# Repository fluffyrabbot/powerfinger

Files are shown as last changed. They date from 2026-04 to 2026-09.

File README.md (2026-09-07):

# PowerFinger

**Open-source assistive input devices. Under $25 BOM. Build one for anyone who
needs it.**

PowerFinger is a family of wearable and handheld pointing devices designed for
accessibility, repairability, and surface agnosticism. Hardware design files —
schematics, PCB layouts, 3D models, BOMs, and assembly docs — are published
under CERN-OHL-S 2.0. Firmware and software, including the companion app, are
published under MIT.

**Primary validation claim:** a user with limited wrist mobility can browse,
click, drag, and scroll on everyday surfaces without host-side remapping
software.

## Philosophy

Computer input is a solved problem for people who can sit at a desk and grip a
mouse. For everyone else — people with limited wrist mobility, repetitive strain
injuries, tremors, amputations, arthritis, or simply no desk — it isn't.

Existing assistive input devices cost $100–$350 and are closed, proprietary, and
fragile. When the vendor disappears, the device becomes e-waste and the user
loses their interface to the digital world.

PowerFinger treats input devices as **prosthetics for digital agency**. The more
redundant ways people have to control things the way they find most natural, the
better as a common good. We design for:

- **Affordability.** $9–$25 BOM depending on variant. The cheapest ring is under
  $10 in components. The first two-ring validation lane targets ~$24 total.
- **Universal design.** Every device works for able-bodied users at their desk
  AND for users with specific accessibility needs. No separate "disability"
  product line.
- **Surface agnosticism as a spectrum.** The optical ring works on most opaque
  surfaces (not glass). The ball+Hall variants are intended for glass, fabric,
  and skin, but those claims stay provisional until the surface protocol is run.
  The IMU variant needs no surface at all. Each variant's limitations are
  documented honestly — see
  [docs/COMBINATORICS.md](docs/COMBINATORICS.md).
- **Composability.** One ring is a mouse. Two rings are a mouse + scroll wheel.
  Three rings are a configurable control surface. The system grows with the
  user's needs.
- **Repairability.** Every part is replaceable. 3D-print a new shell, swap a
  battery, reflash firmware. No planned obsolescence.
- **Privacy.** Fully offline operation. No cloud, no telemetry, no account. Your
  movement data stays on your device.

## Active Program

### Active Validation Lane

- `R30-OLED-NONE-NONE` optical ring pair plus `USB-HUB`
- Goal: prove the no-host-remapping cursor + click + scroll workflow first
- Source of truth: [docs/ACTIVE-LANE-CHECKLIST.md](docs/ACTIVE-LANE-CHECKLIST.md)

### Hedge Lane

- `WSTD-BALL-NONE-NONE` wand
- Use this lane only after the active ring + hub lane clears its gates or if
  the ring fails package-closure / safety reality in a way that forces a
  productization pivot

### Deferred Until Gate 6

- Ball+Hall ring
- Puck variants
- Pro optical-on-ball ring
- OCR / camera and other rich companion features
- IMU hybrids and additional mountings beyond defensive publication coverage

## Form Factors

### Ring

Every ring has a tracking sensor + a click switch + BLE. One ring is the
single-device control loop. Two identical rings plus the hub are the primary
validation lane for the no-host-remapping workflow: cursor + left click on one
finger, scroll + right click on the other. Roles are assigned in software, not
hardware.

```
Middle finger (Ring 1):  move cursor + left click
Index finger  (Ring 2):  scroll      + right click
```

Everything else — drag, double-click, zoom, middle click, modifiers — is
software-defined combinations of those four primitives.

| Variant | BOM | Surface | Resolution |
|---|-----|---|---|
| Optical ring (P0) | ~$9 | Most opaque surfaces (not glass) | 800–2000 CPI |
| Ball+Hall ring (P1) | ~$11 | Target: glass, fabric, skin, and other hard cases | ~15–60 DPI |
| Optical-on-ball ring (Pro) | ~$17 | Target: any rollable surface, pending validation | Up to 12,000 CPI |

Only the optical ring is in the active validation lane. The other ring variants
remain documented for defensive publication and later research.

A USB hub dongle (~$6) is the intended path for composing two or more rings into
a single USB HID mouse without host-side remapping software.

### Wand

A pen-shaped BLE HID pointing device with a ball+Hall sensor at the tip. This
is the hedge lane: a handheld form factor designed for the surfaces and angles
that defeat optical pen mice. It is not the primary validation lane while the
ring + hub proof remains red. ~$14 BOM.

No existing product fills this space. Commercial pen mice ($35–150) use optical
sensors that fail on glass and degrade past ~20 degrees of pen tilt. Assistive
styluses only work on touchscreens. The wand is designed to work across glass,
fabric, blankets, tray tables, and other accessibility-relevant surfaces at
natural pen angles (30–70 degrees), but those claims stay gated until the
hardware protocol is run.

Pen grip reduces forearm pronation from ~42 degrees (flat mouse) to ~28 degrees
— clinically significant for carpal tunnel and RSI. An aluminum or stainless
steel body provides natural weight stabilization for tremor (same principle as
weighted assistive pens).

See [docs/WAND-COMPETITIVE.md](docs/WAND-COMPETITIVE.md) for the competitive
landscape, accessibility case, and patent analysis.

### Other Mountings

The electronics module is invariant; the harness adapts it to any body position.
The ring shell is just one harness. Others: toe ring, knuckle strap, wrist
bracelet, prosthetic mount, headband. Same PCB, same firmware, different
physical mounting. The companion app assigns meaning. These remain design-space
and defensive-publication coverage, not active implementation work.

See [docs/COMBINATORICS.md](docs/COMBINATORICS.md) for the full design space.

## Sensing Mechanisms

| Mechanism | Surface Agnostic? | Moving Parts | BOM | Resolution |
|---|---|---|-----|---|
| Mechanical ball + Hall effect | Target: glass, fabric, skin, and other rollable surfaces | Yes | ~$2 | Low (9–36 ticks/rev) |
| Direct optical (LED) | Most opaque surfaces | None | ~$0.50–4 | Good (800–2000 CPI) |
| Direct laser (VCSEL) | More surfaces than LED | None | ~$2–5 | Good (2000+ CPI) |
| Optical on captive ball | Target: any rollable surface, pending validation | Ball only | ~$5–8 | Excellent (12K CPI) |

## Deferred Capabilities

- **OCR camera** — scan text from physical books/documents, send to companion
  app for local OCR (Tesseract/PaddleOCR), translation, or text-to-speech.
  Requires companion app; pointing function works without it. Deferred until the
  active validation lane clears Gate 4.
- **Guidance laser** — red dot on the surface shows exactly where you're
  pointing/scanning. Deferred until the active validation lane clears Gate 4.

## What Exists Today

PowerFinger is still pre-prototype, but the repo already has a real software
lane. The main difference across directories is how much of each lane is
implementation versus planning:

| Area | Current reality | Start here |
|---|---|---|
| Firmware | Real ESP-IDF targets exist for `ring`, `hub`, `pen`, and `puck`; the verifier covers its own regression tests, host tests, companion protocol, sanitizers, active R30 profile, hub, and strict KiCad by default. | `scripts/verify-firmware-local.sh`, `docs/FIRMWARE-VERIFY-LOCAL.md` |
| Companion | A minimal local Web Serial app now lives under `companion/web/`. It talks to the hub's existing USB CDC text protocol and covers hub info, role assignment, swaps, forget, hub settings, per-ring tuning, live RSSI plus battery/diagnostics inspection, and hub-owned simultaneous-click gesture mapping. | `companion/README.md`, `companion/web/`, `docs/COMPANION-APP-ARCH.md` |
| Hardware | BOM intent files still anchor the lane, and each BOM-backed variant now has a hardware publication packet with a manifest plus assembly/disassembly baseline. The active `R30-OLED-NONE-NONE` ring and `USB-HUB` now also have first-board checklists and validation templates alongside their KiCad/OpenSCAD skeletons; routed PCBs and measured hardware evidence are still pending. | `hardware/README.md`, `hardware/bom/README.md` |
| Docs | Design, validation, accessibility, and IP docs are the most complete part of the repo today. | `docs/` |

## Quick Start

Install CMake, a C compiler, Python, Ruby, Node.js, and KiCad CLI for full local
verification. See [prerequisites and modes](docs/FIRMWARE-VERIFY-LOCAL.md).
Then install the pinned SDK and verify (reports go under `build-verification/`):

```bash
scripts/setup-esp-idf-local.sh
scripts/verify-firmware-local.sh
```

After the one-time bootstrap, `scripts/verify-firmware-local.sh` can run from a
fresh shell and will auto-activate the repo-pinned ESP-IDF 6.1 build candidate.
[Physical hardware qualification remains pending](docs/ESP-IDF-6.1-QUALIFICATION.md).
If you want `idf.py` available in your current shell for direct iteration, run:

```bash
eval "$(scripts/setup-esp-idf-local.sh --export)"
```

The shared verifier runs all mandatory local checks and builds the active
`R30-OLED-NONE-NONE` ring profile and hub. To include the generic development
ring, pen, and puck as well:

```bash
scripts/verify-firmware-local.sh --all
```

For host/contracts/operator/companion checks without SDK or hardware:

```bash
scripts/verify-firmware-local.sh --fast
```

For prerequisite diagnostics without builds:

```bash
scripts/verify-firmware-local.sh --doctor
```

For the local companion app scaffold:

```bash
scripts/serve-companion-local.sh
```

Then open `http://127.0.0.1:4173` in Chrome or Edge and connect to the hub over
Web Serial.

For hardware CAD work on macOS, prefer the current OpenSCAD snapshot cask:

```bash
brew install --cask openscad@snapshot
```

The executable remains `openscad` on `PATH`. Avoid relying on the legacy
`brew install openscad` cask path; Homebrew currently marks that older cask as
deprecated while the snapshot cask tracks the current upstream builds.

See [docs/ACTIVE-LANE-CHECKLIST.md](docs/ACTIVE-LANE-CHECKLIST.md) for the
canonical active-lane checklist, [docs/FIRMWARE-VERIFY-LOCAL.md](docs/FIRMWARE-VERIFY-LOCAL.md)
for the local verification flow, [docs/PROTOTYPE-SPEC.md](docs/PROTOTYPE-SPEC.md)
for the active build spec, [docs/COMBINATORICS.md](docs/COMBINATORICS.md) for
the broader design space, and [docs/GO-NO-GO-RUBRIC.md](docs/GO-NO-GO-RUBRIC.md)
for the validation gate order.

## Project Status

**Pre-prototype.** Architecture, design space, power budget, and competitive
analysis are documented, and the repo already contains real firmware projects
plus a local verification path. Active scope is frozen to the optical ring +
hub validation lane, with the wand as the hedge lane. The companion lane now
has a minimal local Web Serial scaffold, while the hardware tree contains BOM-
backed publication packets, service baselines, first-pass source skeletons, and
active-lane first-board checklists for the ring + hub proof path rather than
finished CAD/PCB drops. See
[docs/ACTIVE-LANE-CHECKLIST.md](docs/ACTIVE-LANE-CHECKLIST.md) for the current
program order and [docs/FIRMWARE-ROADMAP.md](docs/FIRMWARE-ROADMAP.md) for the
firmware build order that runs on dev boards before prototype hardware arrives.

## License

Three artifacts, three licenses:

- **Hardware designs** (schematics, PCB layouts, 3D models, BOMs, assembly
  docs): [CERN-OHL-S 2.0](https://opensource.org/license/cern-ohl-s)
  (strongly reciprocal). See [LICENSE-HARDWARE](LICENSE-HARDWARE).
- **Firmware and software** (ESP-IDF code, companion app): MIT.
  See [LICENSE-SOFTWARE](LICENSE-SOFTWARE).
- **Documentation** (`docs/*.md`, READMEs, assembly guides):
  [CC-BY-SA 4.0](https://creativecommons.org/licenses/by-sa/4.0/).
  See [LICENSE-DOCS](LICENSE-DOCS).

The CERN-OHL-S patent retaliation clause means anyone using these designs who
sues anyone else over them automatically loses their license. The reciprocal
requirement means anyone manufacturing products from these designs must publish
their complete source. See [docs/IP-STRATEGY.md](docs/IP-STRATEGY.md) for full
rationale.

**"PowerFinger" is used descriptively. No trademark is asserted by the
maintainers.** Anyone may build, sell, and modify the design under the
licenses above. Derivative makers are encouraged to use their own product
name and pursue [OSHWA Certified](https://certification.oshwa.org/) status as
a third-party quality signal. See
[docs/NAMING-AND-COMPATIBILITY.md](docs/NAMING-AND-COMPATIBILITY.md) for the
full naming-and-compatibility posture.

## Why "PowerFinger"?

Controlling a computer should require nothing more than a single finger. The
name is corny. It sticks.

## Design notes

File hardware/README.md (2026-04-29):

<!-- SPDX-License-Identifier: CERN-OHL-S-2.0 -->
# Hardware Workspace

This tree is for hardware deliverables that become part of the defensive
publication record.

## Current Repo Status

- The committed hardware artifacts are still BOM-first, but each BOM-backed
  variant now has a publication packet with a manifest plus pre-CAD assembly and
  disassembly guidance.
- The active validation lane now also has initial source skeletons:
  - `ring/R30-OLED-NONE-NONE/{kicad,cad}/`
  - `shared/USB-HUB/{kicad,cad}/`
- Those skeletons are design-starting points, not validated schematics, routed
  PCBs, or mechanically proven CAD.

## Required Structure

- `ring/` — ring-specific CAD, PCB, assembly, and disassembly files
- `wand/` — wand-specific CAD, PCB, assembly, and disassembly files
- `shared/` — reusable modules, accessories, footprints, batteries, connectors,
  and notes
- `bom/` — pre-schematic BOM intent files and later generated BOM exports

## Publication Packets Present Today

- `ring/R30-OLED-NONE-NONE/` — active validation-lane ring packet
- `ring/R30-BALL-NONE-NONE/` — deferred research packet for ball+Hall sensing
- `wand/WSTD-BALL-NONE-NONE/` — wand hedge-lane packet
- `shared/USB-HUB/` — hub packet used by multi-device composition
- `shared/SOURCE-ALTERNATIVES.md` — cross-variant second-source baseline

Each packet includes:

- `MANIFEST.md` — what is actually published now, what is still missing, and the
  repairability boundaries
- `ASSEMBLY.md` — non-destructive assembly expectations for the first hardware drop
- `DISASSEMBLY.md` — battery-safe teardown order and replacement expectations

Active-lane packets may also include:

- `kicad/` — schematic-capture and placement inputs for KiCad work
- `cad/` — editable OpenSCAD source for first-pass mechanical envelopes

## CAD Tooling Note

- On macOS, prefer `brew install --cask openscad@snapshot` for local CAD sanity
  checks and exports.
- The installed CLI remains `openscad`, so packet notes and local scripts should
  keep calling `openscad`.
- Do not rely on the legacy `openscad` Homebrew cask staying healthy; Homebrew
  currently treats that older cask as deprecated while the snapshot cask tracks
  current upstream builds.

## Non-Negotiables

- Every design drop must include assembly and disassembly instructions.
- Every battery selection must satisfy `docs/BATTERY-SAFETY.md`.
- Claims in hardware notes must match `docs/GO-NO-GO-RUBRIC.md`.
- Do not mark unvalidated variants as production-ready.
- Do not start secondary hardware variants before the active ring + hub packets
  have concrete first-board outputs and linked validation evidence.

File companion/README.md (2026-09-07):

# Companion App

The companion app is optional configuration software, not a runtime dependency.

## Current Repo Status

- A minimal dependency-free Web Serial client now lives in `companion/web/`.
- It talks to the hub's existing USB CDC transport from Chrome or Edge on
  `localhost`.
- Implemented hub commands today: `GET_HUB_INFO`, `GET_ROLES`, `GET_RINGS`,
  `GET_RING_INFO`, `GET_RING_SETTINGS`, `GET_RING_DIAGNOSTICS`, `SET_RING_DPI`,
  `SET_RING_DEAD_ZONE_TIME`, `SET_RING_DEAD_ZONE_DISTANCE`, `SET_HUB`,
  `GET_GESTURES`, `SET_GESTURE`, `SET_ROLE`, `SWAP_ROLES`, and `FORGET_RING`.
- `ROLE_SWAP` remains accepted by the hub parser as a compatibility alias for
  `SWAP_ROLES`.
- The current gesture UI covers the shipped hub subset only: simultaneous-click
  triggers (`0x01`-`0x04`) mapped to disabled, middle-click, back, or forward
  (`0x00`-`0x03`).
- No Flutter, mobile, or packaged desktop app scaffold is checked in yet.

## Current Scope

- No host-side input interception
- No cloud dependency
- No workflow automation dependency
- No blocking role in P0 validation
- Richer app work stays deferred until the active ring + hub lane clears Gate 4

## Run It Locally

```bash
scripts/serve-companion-local.sh
```

Then open `http://127.0.0.1:4173` in Chrome or Edge and connect to the hub over
Web Serial.

The dependency-free protocol test is part of the repository verifier:

```bash
scripts/verify-firmware-local.sh --fast
```

This keeps companion verification offline and does not require a browser,
account, cloud service, or connected device.

## What The Scaffold Covers

- Hub snapshot via `GET_HUB_INFO`
- Known-ring list with live connected/disconnected state via `GET_RINGS`
- Per-ring snapshot plus live RSSI readback via `GET_RING_INFO`
- Per-ring live tuning readback via `GET_RING_SETTINGS`
- Per-ring battery and diagnostics readback via `GET_RING_DIAGNOSTICS`
- Hub-owned settings writes via `SET_HUB` (`usb_poll_ms`, `scan_policy`,
  `expected_rings`)
- Per-ring live tuning writes via the `SET_RING_*` relay commands
- Hub-owned simultaneous-click gesture mapping via `GET_GESTURES` /
  `SET_GESTURE`
- Per-ring reassignment via `SET_ROLE`
- Two-ring swap via `SWAP_ROLES`
- Ring removal via `FORGET_RING`
- Raw command console plus transcript for protocol debugging, with the modeled
  panels staying in sync for the current shipped command subset

## Current Gaps

- No direct BLE mode for single-ring tuning
- No OTA UX
- No packaged installable app

Those gaps are intentional for the current program order, not missing blockers
for the active validation lane.

## What To Read First

- `docs/COMPANION-APP-ARCH.md` - architecture, transport, and UX sketch
- `docs/MULTI-RING-PROTOCOL.md` - hub command contract
- `companion/web/` - static local app scaffold
- `firmware/hub/components/companion_cdc/` - USB CDC transport
- `firmware/hub/components/companion_session/` - line-oriented session layer
- `firmware/hub/components/companion_protocol/` - command parser and responses

## Expected Future Responsibilities

- OTA update UX
- Packaged desktop and mobile variants
- Broader hub policy/configuration beyond the current shipped settings subset

See `docs/COMPANION-APP-ARCH.md` for the deferred architecture sketch.

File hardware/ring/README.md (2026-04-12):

<!-- SPDX-License-Identifier: CERN-OHL-S-2.0 -->
# Ring Hardware

This directory is reserved for ring-specific hardware deliverables.

## Current Repo Status

- The current ring-side publication packets are:
  - `R30-OLED-NONE-NONE/`
  - `R30-BALL-NONE-NONE/`
- `R30-OLED-NONE-NONE/` now includes first-pass `kicad/` and `cad/` skeletons
  plus first-board checklists for the active optical validation lane.
- `R30-BALL-NONE-NONE/` remains BOM + service-baseline only and is deferred
  until the active ring + hub lane clears its gates.
- Those packets are grounded in the BOM intent files in `hardware/bom/` and define
  the minimum serviceability baseline for the first real hardware drop.
- The first hardware lane to prove itself remains the optical ring pair + hub
  validation path described in the top-level README.

## Expected Contents Per Variant

- `kicad/` or equivalent PCB source
- `cad/` or equivalent shell/mechanical source
- `ASSEMBLY.md`
- `DISASSEMBLY.md`
- `TEST-NOTES.md`

## Minimum Metadata

- Variant ID, sensing mechanism, angle, and intended use case
- BOM estimate at prototype quantity
- Finger-size parameters or sizing assumptions
- Surface limitations stated honestly

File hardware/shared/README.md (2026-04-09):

<!-- SPDX-License-Identifier: CERN-OHL-S-2.0 -->
# Shared Hardware

Use this directory for components and notes reused across ring and wand builds.

## Good Fits

- Battery selection notes
- Connector footprints and pinouts
- ESP32 module placement / antenna keep-out references
- Common charge/power subcircuits
- Shared assembly practices and repair notes
- Accessory hardware that serves multiple form factors, such as `USB-HUB/`
- Cross-variant source-alternative tables such as `SOURCE-ALTERNATIVES.md`

## Current Repo Status

- `USB-HUB/` now includes first-pass `kicad/` and `cad/` skeletons for the
  active multi-device composition lane.
- Other shared files in this directory are still documentation and sourcing
  baselines rather than finished hardware sources.

If a file is specific to one form factor, keep it under `ring/` or `wand/`
instead.

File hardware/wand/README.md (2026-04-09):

<!-- SPDX-License-Identifier: CERN-OHL-S-2.0 -->
# Wand Hardware

This directory is reserved for wand-specific hardware deliverables.

## Current Repo Status

- No wand KiCad or CAD sources are checked in yet.
- The current wand-side publication packet is `WSTD-BALL-NONE-NONE/`, grounded in
  `hardware/bom/WSTD-BALL-NONE-NONE.csv`.
- The wand remains the hedge lane rather than the active validation lane.
- The packet documents the current intended service path without claiming the
  package geometry is already proven.

## Expected Contents Per Variant

- `kicad/` or equivalent PCB source
- `cad/` or equivalent body/tip source
- `ASSEMBLY.md`
- `DISASSEMBLY.md`
- `TEST-NOTES.md`

## Minimum Metadata

- Variant ID, sensing mechanism, and intended accessibility use case
- BOM estimate at prototype quantity
- Supported angle range as tested, not assumed
- Surface limitations stated honestly

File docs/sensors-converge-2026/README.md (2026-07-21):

<!-- SPDX-License-Identifier: CC-BY-SA-4.0 -->
# Sensors Converge 2026 — Partnership Outreach Triage

**Event:** May 5–7, 2026, Santa Clara Convention Center.
**Status of this doc:** Self-facing prep notes. Not for external distribution.

This directory triages confirmed-exhibiting companies into outreach tiers and
gives a one-page strategy per company. The goal is to walk the floor with a
ranked target list, a known posture per booth, and a clear post-show plan.

## Recommended posture for the 2026 show: SOFT CONTACT

The project is pre-prototype. The GitHub repo is too rough to show without
forming an impression that's hard to overwrite later. There is no working
ring and no one-pager you'd hand to a stranger.

**Read [`SOFT-CONTACT-MODE.md`](SOFT-CONTACT-MODE.md) first.** It is the
current default for the 2026 show. The reframe: information visit, not pitch
visit. Booth conversations exist to acquire named contacts and a justification
to email them later, when the project is ready. The conversion event is a
follow-up email weeks or months out — not a booth pitch.

[`FLOOR-PLAYBOOK.md`](FLOOR-PLAYBOOK.md) describes the pitch-mode posture and
becomes the right doc only when (1) there's a working ring, (2) there's a
one-pager you'd be proud of, (3) the GitHub README is presentable, and (4)
at least one consumer-tier BOM has validated power numbers. Use it at a later
event, not at Sensors Converge 2026.

The triage, floor-walk order, and per-vendor docs below apply to **both**
postures. Only the booth-conversation behavior differs.

If a **Shenzhen visit is also on the 2026 calendar**, read
[`SHENZHEN-PAIRING.md`](SHENZHEN-PAIRING.md) before finalizing the floor
plan. Several Tier S booths (Murata, EM Microelectronic, Mouser, Excelitas)
become deferrable to Shenzhen because their value is supply-chain rather
than relationship. The shrunken Sensors Converge floor walk is 5 booths,
not 12.

If the Shenzhen / Seeed conversation needs a factory-facing artifact, use
[`SHENZHEN-SEEED-QUOTE-PACKET.md`](SHENZHEN-SEEED-QUOTE-PACKET.md). It is the
current repo-backed quote starter: hub quote first, ring DFM/pre-fab review
until board-house output constraints and physical fit/stackup evidence close.
When a factory reply arrives, scaffold a dated intake directory under
[`factory-replies/`](factory-replies/) before updating the response-capture
sheet or downstream vendor docs.

## Caveats

- "Confirmed" here means surfaced in (a) the smallworldlabs A–F slice that is
  publicly fetchable or (b) Questex / Fierce Sensors press coverage of headline
  sponsors. The full directory is 150+ exhibitors; the M–Z range was not
  fetchable. Verify each booth assignment in the on-site mobile app before
  arriving.
- Three of the most directly load-bearing silicon partners — **PixArt**,
  **Nordic**, and **Espressif** — are not visible in the confirmed list.
  Search the on-site app for them; if absent, pursue them through their own
  partner programs after the show, not on the floor.
- This is a partnership-prospecting trip, not a customer-prospecting trip. The
  show's audience is engineers and component buyers; PowerFinger has no
  customers in that audience. The value is silicon, modules, distribution, and
  fab introductions — not orders.

## Pre-show prep checklist (soft-contact mode — current)

- [ ] **Read [`SOFT-CONTACT-MODE.md`](SOFT-CONTACT-MODE.md) end-to-end** the
      day before. Internalize the opening lines and the graceful close.
- [ ] Personal business cards: name + email only. No project name, no GitHub
      URL. ~$25 from MOO / Vistaprint, 24-hour turnaround.
- [ ] Personal email separate from any project-tied identity.
- [ ] Pre-load the floor map and mark the 12 confirmed booths in two colors:
      Tier S (must-visit) and Tier A (visit if time).
- [ ] Pre-pick 1–2 specific technical questions per Tier S booth from the
      "Questions to ask at booths" section of `SOFT-CONTACT-MODE.md`.
- [ ] Memorize one of the three opening lines and the graceful close. Practice
      out loud five times.
- [ ] Paper notebook + pen. One page per conversation; capture name, email,
      what you asked, what they said, the date.

### Pitch-mode prep checklist (deferred — for a later event)

The following apply only when switching back to
[`FLOOR-PLAYBOOK.md`](FLOOR-PLAYBOOK.md), i.e. when the four readiness
conditions are met:

- [ ] Print 50 single-page project one-pagers (BOM, power numbers, surface
      compatibility table, license posture, GitHub URL). One side, no fluff.
- [ ] Bring a working ring or a non-functional 3D-printed shell with a
      populated PCB visible.
- [ ] Have a 30-second pitch and a 2-minute pitch rehearsed.
- [ ] Pre-write a follow-up email template per tier.

## Tier S — must visit, specific ask prepared

These four are the highest leverage on the floor. Each can replace multiple
BOM lines or collapse a regulatory step. Prepare a specific ask before going.

| # | Company | One-line angle | Doc |
|---|---|---|-----|
| 1 | STMicroelectronics | STM32WB/WBA as full nRF52840 alternative + sensor portfolio + ST Partner Program | [01-stmicroelectronics.md](01-stmicroelectronics.md) |
| 2 | Microchip | PIC32CX-BZ / WBZ family BLE + active maker/edu program + design-in support at low volume | [02-microchip.md](02-microchip.md) |
| 3 | Bosch Sensortec | BMI / BHI series IMU for the IMU-variant ring; on-chip fusion = simpler firmware | [03-bosch-sensortec.md](03-bosch-sensortec.md) |
| 4 | Murata | Pre-certified BLE modules collapse FCC/CE/RED prescan; biggest regulatory de-risk | [04-murata.md](04-murata.md) |

## Tier A — visit if time, narrower fit

| # | Company | One-line angle | Doc |
|---|---|---|-----|
| 5 | TDK InvenSense | ICM-series IMU + MEMS + piezo film for Pro click | [05-tdk-invensense.md](05-tdk-invensense.md) |
| 6 | Analog Devices | ADCs (piezo click), IMUs, ADuCM4050 BLE MCU; AppNote depth | [06-analog-devices.md](06-analog-devices.md) |
| 7 | ams OSRAM | Optical/proximity sensing IP; tip detection on the wand | [07-ams-osram.md](07-ams-osram.md) |

## Tier B — drive-by only if convenient

| # | Company | One-line angle | Doc |
|---|---|---|-----|
| 8 | EM Microelectronic | EM9304/EM9305 ultra-low-power BLE; coin-cell wearable angle | [08-em-microelectronic.md](08-em-microelectronic.md) |
| 9 | Mouser Electronics | Distribution; "buy the BOM" merchandising / open-hardware showcase | [09-mouser.md](09-mouser.md) |
| 10 | Edge Impulse | TinyML for IMU gesture classification; speculative | [10-edge-impulse.md](10-edge-impulse.md) |
| 11 | Ceva | Sensor fusion IP licensing; probably wrong scale for the project | [11-ceva.md](11-ceva.md) |
| 12 | Excelitas | Photonics / VCSEL; only matters if a laser variant is pursued | [12-excelitas.md](12-excelitas.md) |

## Floor-walk order (recommended)

1. **Open with Murata.** Cheapest conversation to win and biggest immediate
   regulatory unlock. A pre-cert module is the kind of thing where five minutes
   with an FAE replaces a month of prescan work.
2. **Bosch Sensortec next.** They're the IMU vendor that matters; the BHI
   smart-sensor-hub story is exactly the kind of thing PowerFinger could
   showcase.
3. **STMicroelectronics and Microchip back-to-back.** These are the two big
   silicon platforms competing for your design. Visit them in sequence so you
   can compare what each is willing to offer for a design win.
4. **TDK + ADI + ams** in any order — Tier A, narrower fit, shorter visits.
5. **Tier B as drive-bys** if there's time on day 2 or day 3.

## What "win" looks like per conversation (soft-contact mode)

For each Tier S / Tier A booth, the minimum viable outcome is:

- **A named FAE or developer-relations email**, given willingly after a 2–5
  minute technical conversation. That email + the specific question you
  asked = your justification to follow up months later.
- **Their literature in hand** — dev kit catalog, partner-program brochure,
  app-note pointer.
- **One useful technical answer logged** in your notebook for reference (idle
  current numbers, BSX licensing posture, antenna keepout rules, etc.).

If a booth offers none of those, mark it "no path" and do not pursue post-show.

## What "win" does NOT look like

- A business card with no email exchanged in either direction (cards alone
  are weak signal; an explicit email handover is the contract).
- An "email our partnerships inbox" hand-off — that inbox is a dead letter
  office for projects at PowerFinger's scale.
- A booth conversation in which you ended up pitching the project despite
  the soft-contact plan. If this happens, log it but treat the contact as
  weakened — the next email needs to overcome the immature first impression.

### Pitch-mode "win" criteria (deferred)

What "win" looks like when in pitch mode (per `FLOOR-PLAYBOOK.md`) — for
reference at a future event:

- Named contact in their partner / design-win / maker program with willingness
  to take a follow-up.
- Free or sampled parts tied to a promise of public reference-design
  publication.
- FAE / app-engineer hours offered for a specific firmware or BOM question.
- Listing or featured-project placement in their open-hardware showcase or
  developer blog.

## Post-show (soft-contact mode)

- **Same night:** log every conversation into the per-vendor doc's "Sensors
  Converge 2026 booth notes" section. Capture name, email, what you asked,
  what they said, the date.
- **Triage:** mark Tier S contacts as starred for follow-up; Tier A as
  "maybe"; Tier B as archive-unless-engaged.
- **Schedule the follow-up.** Calendar reminder for the date you expect to
  be ready. Do **not** send same-night "nice to meet you" emails — a
  content-free email weakens the future warm follow-up.
- **The follow-up email is the conversion event** — see
  [`SOFT-CONTACT-MODE.md`](SOFT-CONTACT-MODE.md) for the template.
- Update [`../REFERENCE-MANUFACTURERS.md`](../REFERENCE-MANUFACTURERS.md) and
  [`../OUTREACH.md`](../OUTREACH.md) with anything learned that updates the
  vendor stack or the partner pipeline.

### Pitch-mode post-show (deferred)

For reference at a future event in pitch mode (per `FLOOR-PLAYBOOK.md`):

- Within 48 hours: email each Tier S contact with a recap, the one-pager
  attached, and one specific next-step question.
- Within one week: Tier A follow-ups.
- Tier B contacts can wait or be skipped.

## See also

- [`SOFT-CONTACT-MODE.md`](SOFT-CONTACT-MODE.md) — **read first.** Current
  recommended posture for the 2026 show: information visit, no pitch.
  Includes opening lines, questions to ask, the graceful close, and the
  follow-up email template that is the actual conversion event.
- [`FLOOR-PLAYBOOK.md`](FLOOR-PLAYBOOK.md) — pitch-mode booth strategy.
  Defer until working ring + polished one-pager + presentable GitHub +
  validated power numbers. Useful at a later event.
- [`SHENZHEN-PAIRING.md`](SHENZHEN-PAIRING.md) — coordinates the Sensors
  Converge floor walk with a Shenzhen visit. Deferrable booths, must-visits,
  and Shenzhen factory targets that replace deferred booth conversations.
- [`SHENZHEN-SEEED-QUOTE-PACKET.md`](SHENZHEN-SEEED-QUOTE-PACKET.md) —
  repo-backed quote starter for Seeed/Shenzhen conversations.
- [`../OUTREACH.md`](../OUTREACH.md) — accessibility-community outreach (Tier
  3+ in the broader partnership stack: Microsoft Adaptive, Logitech, MMC,
  e-NABLE, etc.). Sensors Converge does not address that tier.
- [`../IP-STRATEGY.md`](../IP-STRATEGY.md) — the CERN-OHL-S posture every
  silicon partner needs to understand before a design-in conversation makes
  sense.
- [`../REFERENCE-MANUFACTURERS.md`](../REFERENCE-MANUFACTURERS.md) — where any
  contract-manufacturer leads from the show should be logged.
- [`../CONSUMER-TIERS.md`](../CONSUMER-TIERS.md) — the Standard / Pro tier model
  that frames every silicon swap conversation.

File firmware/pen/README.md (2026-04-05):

# PowerPen Firmware — WSTD-BALL-NONE-NONE

ESP-IDF build target for the core PowerPen prototype. Shares most components
with the ring firmware via `EXTRA_COMPONENT_DIRS`; the pen target adds
target-specific configuration plus a local `pen_wake/` component for DRV5032
spurious-wake debounce and runtime wake-mask filtering.

## Build

```bash
cd firmware/pen
idf.py build
idf.py -p /dev/ttyUSBx flash
```

## Current Status

- Host-side verification covers the pen-specific dual-click path and DRV5032
  wake debounce (`test_click_pen`, `test_pen_wake_debounce`).
- The pen target now resolves both `firmware/pen/components/` and
  `firmware/ring/components/`.
- Real ESP-IDF build, pairing, surface tracking, wake current, and latency
  still require local hardware and an installed ESP-IDF toolchain.

## What's Different from Ring

| Concern | Ring | PowerPen |
|---|---|---|
| Sensor | PAW3204 optical (SPI) | Ball+Hall 4x DRV5053 (ADC) |
| Click | Single dome (one GPIO) | Barrel switch + tip dome (two GPIOs) |
| Dead zone | Always on (dome press moves sensor) | Per-click-source: barrel off, tip on |
| Pin map | See `ring/sdkconfig.defaults` | See `pen/sdkconfig.defaults` |
| BLE device name | "PowerFinger Ring" | "PowerPen" |
| Hall power gating | N/A for optical ring | MOSFET gate on Hall VCC rail |
| Wake sensor | N/A (optical has motion detect pin) | DRV5032 digital Hall switch (0.54µA) + spurious wake debounce |
| Wake GPIOs | Single dome pin | Three-GPIO bitmask (barrel, tip dome, DRV5032) |
| VBAT divider | TBD | 10MΩ/10MΩ (0.165µA sleep draw) |
| PCB | Flex or rigid-flex | Rigid strip (~8mm wide) |
| State machine | `ring_state_t` / `ring_event_t` | Same — reused unchanged |

## Shared Components (from ring/)

Shared unchanged:
- `hal/` — GPIO, SPI, ADC, timer, sleep, storage, OTA, BLE
- `ble_hid/` — HID report descriptor, GAP handler
- `sensors/` — `sensor_interface.h` (ball+Hall driver implements this)
- `click/calibration.c` — Sensor zero-offset calibration

Shared with implemented pen-specific extensions:
- `click/` — source-aware click polling plus `click_pen.c` for barrel + tip
- `click/dead_zone.c` — instanceable dead-zone contexts; pen uses tip-only suppression
- `power/` — wake GPIO bitmask, Hall gate-off on failed calibration, runtime wake-mask override
- `diagnostics/` — snapshot carries `drv5032_wake_enabled` and `spurious_wake_count`

Pen-local:
- `pen/components/pen_wake/` — DRV5032 spurious-wake debounce and GPIO8 wake disable/restore logic

## Firmware Tasks

See `docs/POWERPEN-SPEC.md` sections PP1–PP6 for the incremental task list.

## Spec

Full specification: [docs/POWERPEN-SPEC.md](../../docs/POWERPEN-SPEC.md)

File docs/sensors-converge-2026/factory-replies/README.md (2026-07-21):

<!-- SPDX-License-Identifier: CC-BY-SA-4.0 -->
# Factory Reply Evidence Intake

This directory is the source-controlled landing zone for Shenzhen / Seeed
factory replies tied to the current packet:

- Primary path: `USB-HUB` PCB fabrication and assembly quote plus
  connector/enclosure DFM review.
- Optional path: `R30-OLED-NONE-NONE` DFM/pre-fab review annex only, if the
  factory explicitly accepts the annex.

Create one dated directory per factory reply. Do not reuse a directory for a
later thread, revised quote, or second factory contact.

## Scaffold Command

From the repository root:

```sh
scripts/scaffold-shenzhen-seeed-factory-reply.py YYYY-MM-DD
```

If the same reply also includes an accepted R30 DFM/pre-fab annex:

```sh
scripts/scaffold-shenzhen-seeed-factory-reply.py YYYY-MM-DD --include-r30-annex
```

The default directory shape is:

```text
docs/sensors-converge-2026/factory-replies/YYYY-MM-DD-seeed-fusion-propagate-usb-hub-reply/
  README.md
  incoming/
  quote-files/
  source-return/
  USB-HUB-SUBSTITUTIONS.md
  USB-HUB-DFM-ASKS.md
  SOURCE-RETURN-INDEX.md
  R30-OLED-NONE-NONE-DFM-ANNEX/        # only with --include-r30-annex
```

## Capture Rules

- Put raw email exports, screenshots, and attachments in `incoming/`.
- Put quote sheets, invoices, DFM reports, BOM/CPL/POS import notes, and
  payment terms in `quote-files/`.
- Put factory-returned editable source and CAM-only artifacts in
  `source-return/`, then summarize them in `SOURCE-RETURN-INDEX.md`.
- Transcribe proposed substitutions into `USB-HUB-SUBSTITUTIONS.md`.
- Transcribe non-substitution DFM requests into `USB-HUB-DFM-ASKS.md`.
- Reference the dated directory from
  [`../SHENZHEN-FACTORY-RESPONSE-CAPTURE.md`](../SHENZHEN-FACTORY-RESPONSE-CAPTURE.md)
  before changing `docs/REFERENCE-MANUFACTURERS.md` or
  `docs/VENDOR-VERIFICATION.md`.

Quote files prove that a quote or factory answer was received. They do not
prove build yield, realized COGS, physical fit, RF behavior, connector
retention, source compatibility, or independent distributor availability.

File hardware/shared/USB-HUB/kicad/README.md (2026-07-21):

<!-- SPDX-License-Identifier: CERN-OHL-S-2.0 -->
# USB-HUB KiCad Packet

This directory is the schematic/layout starting point for the active hub
accessory lane.

The packet now includes a first routed board-source pass. It is still a first
board, not measured hardware evidence: connector strain, host clearance, and
enclosure fit must be validated before the lane moves to secondary variants.

## Current Source Files

- `usb_hub.kicad_sch` — root sheet for the active hub lane
- `sheets/usb_and_power.kicad_sch`
- `sheets/mcu_radio.kicad_sch`
- `sheets/controls_and_indicators.kicad_sch`
- `usb_hub.kicad_pcb` — stepped USB-A direct-plug first-board pass
- `usb_hub.kicad_pro` — local KiCad project settings for this packet
- `sym-lib-table` — local project symbol table for KiCad CLI/library checks
- `PowerFinger.kicad_sym` — local hub-specific first-board symbols
- `fp-lib-table` — local project footprint table for KiCad CLI/library checks
- `PowerFinger_USB.pretty/` — local footprint library for the direct-plug USB-A
  connector, first-board ESP32-S3 module land pattern, service pads, clamp
  holes, and packet-pinned commodity footprints
- `FABRICATION-OUTPUTS.md` — checked-in note for regenerating and reviewing the
  local Gerber, drill, POS, active-BOM/POS, and archive outputs
- `BOARD-HOUSE-OUTPUT-CONSTRAINTS.md` — board-house intake questions tied to
  the current generated-output state

## What Belongs Here Next

- `INTERFACE-CONTRACT.md` — first-pass native USB and recovery-pin contract
- `BRINGUP-SERVICE-MATRIX.md` — mandatory recovery access and first-board checks
- `CAPTURE-BINDINGS.md` — which active BOM lines need stock, vendor, or custom binding
- `P0-COMPONENT-LOCKS.md` — exact first-board USB and power parts for the active dongle lane
- `SCHEMATIC-CAPTURE.md` — sheet split, net naming, and capture order
- `BOM-BLOCK-MAP.md` — map the BOM into the first hub schematic
- `RECOMMENDED-FIRST-CAPTURE.md` — the recommended first board scope
- `../FIRST-BOARD-CHECKLIST.md` — the execution checklist that decides when this
  packet is allowed to move on to secondary variants

## Capture Order

1. Native USB path and `VBUS_5V` entry from the connector
2. `RT9080-33GJ5` 5V-to-3.3V regulation, decoupling, and connector-side protection
3. Boot/reset and bring-up access
4. Status LED and any test pads

## First Board Reality

- The current PCB outline is stepped: the USB-A nose carries the SOFNG USB-05
  shell-tab pads and widens to a `54 x 26 mm` module/service body behind the
  plug. That is more honest than the earlier placeholder, but adjacent-port
  host clearance is now an explicit mechanical risk to verify.
- `R1` is resolved as two 22R 0402 resistors (`R1A`, `R1B`) placed at the
  ESP32-S3 side of the native USB pair. `C5` / `C6` remain unconnected
  no-BOM 0402 mechanical placeholders in this pass; shunt capacitors are not
  part of the clean first-board routing until SI evidence calls for them.
- `U1` is rotated so the ESP32-S3 antenna keep-out lands at the rear of the
  dongle, away from the USB shell and away from service pads.
- `SW1` is a pad-actuated `BOOT_N` service path for this pass; `EN`, `BOOT_N`,
  UART0, power, and ground pads remain probeable along the reopenable seam.
  USB data continuity is inspected at trace/connector access points rather than
  dedicated connected USB data service pads in this pass. `TP6`-`TP9` are now
  explicit no-BOM schematic service pads matching the routed board footprints.
- The schematic now carries the routed board's common ground, EN RC support,
  status LED path, and local decoupling instead of leaving those as PCB-only
  drift. The USB shell tabs and ESP32-S3 module ground pads are now explicit
  schematic pins tied to ground, and PCB footprint metadata matches the locked
  schematic fields. KiCad CLI verification is active on this packet: the current
  schematic ERC and PCB DRC pass at error severity with local symbol and
  footprint libraries loaded, the all-severity schematic ERC reports 0
  messages, and the all-severity PCB DRC pass is clean with 0 unconnected items
  and 0 schematic parity issues.
  `usb_hub.kicad_pro` intentionally ignores `lib_footprint_mismatch` because
  the first-board footprints are now source-controlled in
  `PowerFinger_USB.pretty/`; the remaining blockers are measured hardware
  evidence, not KiCad ERC/DRC drift.
- Local fabrication-review outputs are generated by
  `scripts/generate-usb-hub-fabrication-review.py` under
  `build-kicad/USB-HUB/fabrication-review/`. `FABRICATION-OUTPUTS.md` records
  the current output hashes and the active-BOM/POS review status; those outputs
  are reproducible review artifacts, not source-controlled fabrication release
  proof.

## Hard Constraints

- Native USB is load-bearing for the hub. Do not insert an unnecessary USB-UART
  bridge into the normal data path.
- Treat [PLACEMENT-CONSTRAINTS.md](PLACEMENT-CONSTRAINTS.md) as a blocker list.
- Connector mechanical support matters as much as the schematic.
- `VREG_3V3` must be generated by the captured board power tree, not borrowed
  from a hidden dev-board assumption.
- The current P0 path locks `J1`, `U2`, and `D1`; those exact parts are now
  represented in schematic and PCB source.
- `usb_and_power.kicad_sch` now contains the locked USB/power symbols plus the
  `R1A` / `R1B` 22R native-USB decision.
- The first PCB source captures connector reinforcement geometry, but that is
  not a substitute for the retention evidence in
  `../CONNECTOR-RETENTION-VERIFY.md`.
- Close `../FIRST-BOARD-CHECKLIST.md` and
  `../CONNECTOR-RETENTION-VERIFY.md` before treating this lane as hardware-ready.

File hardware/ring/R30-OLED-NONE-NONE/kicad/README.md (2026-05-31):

<!-- SPDX-License-Identifier: CERN-OHL-S-2.0 -->
# R30-OLED-NONE-NONE KiCad Skeleton

This directory is the PCB/schematic starting point for the active optical ring
lane. It is intentionally honest about its state: the first routed PCB pass now
exists, and the power/USB plus MCU/radio plus sensor/click sheets now include
first-pass symbols. The current KiCad wrapper snapshot is ERC/DRC/parity clean,
but fabrication outputs and physical first-board evidence are still separate
packet gates.

## Current Source Files

- `r30_oled_none_none.kicad_sch` — root sheet for the active optical ring lane
- `r30_oled_none_none.kicad_pcb` — first rigid P0 routed board pass, with
  footprint locks, placement zones, antenna keep-outs, and charge-path routing
- `FABRICATION-OUTPUTS.md` — local Gerber/drill/POS plus active-BOM/POS review
  commands, hashes, and caveats for the DRC-clean first-board source
- `BOARD-HOUSE-OUTPUT-CONSTRAINTS.md` — prototype-house intake checklist for
  turning the local outputs into specific pre-fab feedback without claiming
  physical ring closure
- `sheets/power_and_charge.kicad_sch`
- `sheets/mcu_radio.kicad_sch`
- `sheets/sensor_and_click.kicad_sch`
- `sheets/usb_and_service.kicad_sch`

## What Belongs Here Next

- Local symbol and footprint references only where upstream libraries are not
  enough
- Plot and fabrication presets once routing exists
- `INTERFACE-CONTRACT.md` — first-pass electrical pin contract for capture and firmware
- `CAPTURE-BINDINGS.md` — which active BOM lines need stock, vendor, or custom binding
- `SCHEMATIC-CAPTURE.md` — sheet split, net naming, and capture order
- `BOM-BLOCK-MAP.md` — turn the BOM into schematic blocks without drift
- `RECOMMENDED-FIRST-CAPTURE.md` — the recommended P0 scope boundary
- `../FIRST-BOARD-CHECKLIST.md` — the execution checklist that decides when this
  packet is allowed to move on to secondary variants

## Capture Order

1. Power tree: protected LiPo, TP4054 charge path, RT9080 LDO, fixture-fed
   VBUS service jumper, NTC divider
2. MCU/module block: `ESP32-C3-MINI-1-N4` with antenna keep-out reserved first
3. Sensor block: PAW3204-class optical sensor plus matching lens and aperture
4. Human input block: dome switch and any required debounce/passive support
5. Off-board USB service/programming path for charging plus firmware bring-up

## First Routed Board Pass

`r30_oled_none_none.kicad_pcb` locks the current P0 direction:

- rigid validation board with separate power/service, sensor/click, and
  MCU/radio zones
- ESP32-C3-MINI-1 antenna end facing the shell exterior, with copper and
  antenna keep-outs marked before any convenience routing; the external
  keep-out forbids tracks, vias, pads, and copper pour while allowing the owning
  module footprint whose antenna courtyard reaches the board edge
- bottom-side PAW3204 placement centered on the `6.2 mm` optical aperture datum
  recorded as a `Cmts.User` alignment circle, not an internal `Edge.Cuts`
  fabrication cutout through the populated PCB
- off-board same-net battery service pads for a replaceable protected-cell
  harness or fixture; no onboard JST-SH receptacle body is claimed
- Off-board same-net USB service pads for USB2 data, VBUS, CC pulldowns, GND,
  and shield continuity; charge/program service now requires a fixture or pogo
  harness rather than an onboard USB-C receptacle
- TP4054 path routed through a non-BOM fixture-fed VBUS service jumper,
  `20 kohm` RPROG, RT9080 regulation, and an NTC divider near the battery
  service pads
- MCU/radio and sensor/click sheets populated with first-pass symbol
  counterparts for the routed `U1`, `U2`, `SW1`, decoupling, sense testpads,
  and sensor bring-up pads
- routed sheet nets promoted to passive global labels where they intentionally
  match flat PCB net names, with the project-local `Q1` VBUS service jumper,
  aligned USB ESD D+/D- labels, and service shield pads mapped to `SH`
- `J_BAT` backed by a project-local first-board symbol that models `MP1`/`MP2`
  as GND-tied shield/service pads, so schematic/PCB parity is clean
- first routing cleanup of USB-C SMT contact pad length, snap-dome contact
  geometry, and wrong first-pass power/USB endpoint coordinates
- second routing cleanup of the SDIO/motion fanout, VBUS-detect dogleg, long
  VBUS detector feed, and minimum routed trace width
- charger-service cleanup that replaces the active `Q1`/`R4`/`Q2`/`R6`
  charge-gate with a non-BOM fixture-fed VBUS jumper into TP4054 `VCC`
- USB/D1 fanout cleanup that nudges `D1` upward, doglegs J1 `A6`/`A7` before
  the drop, and separates the long `USB_D+`/`USB_D-` lanes into U1
- connector-edge cleanup that extends the fixed J1 service lip leftward and
  ties J1 `A4`/`A9`/`B4`/`B9` as one VBUS contact group
- connector-cluster cleanup that moves `R2B` beside J1 `B5`, shifts the local
  VBUS trunk inward, and moves `NTC1`/`R3` out of D1's immediate `USB_D+`
  corridor
- A-side USB data cleanup that moves the J1 `A6`/`A7` to D1 escape onto `B.Cu`
  under the charger cluster and re-enters beside D1 with the `USB_D-` entry via
  shifted left for clearance
- mirrored USB-C data cleanup that routes J1 `B6`/`B7` into the same escape
  through separated `B.Cu` lanes and a short front-layer `USB_D-` overpass,
  while leaving D1 VBUS disconnected because the direct branch still regresses
  total DRC; route-only D1 GND/VBUS service-island attempts also regress, so the
  follow-up needed footprint/placement movement rather than another local
  stitch
- D1 footprint cleanup that replaces the rail-clamped USBLC6 SOT-23-6 island
  with a rail-less TPD2E2U06DCK-class SC-70/SOT-323 data-line shunt, removing
  the D1 VBUS branch from the constrained service-edge pocket
- service-edge GND/shield spine that ties the J1 ground contacts and shell
  stakes, pulls `R2B` and `R1` into the lower return, reaches `J_BAT` `MP1`
  from the upper return, and drops D1/NTC ground through a local B-side via
  without reintroducing VBUS-clamped ESD protection
- battery-side GND fanout cleanup that doglegs `R8`/`J_BAT` `MP2` away from
  the `VBAT_SENSE` trace, ties `J_BAT` pad 2 into that local return, moves
  `J_BAT` `MP1` onto a B-side return via, and joins `R2A`/left `SW1`/`Q2`
  source into one local ground chain
- via-rule cleanup that brings the six remaining sub-minimum first-board vias
  from `0.46` mm diameter / `0.20` mm drill to the board-rule minimum
  `0.50` mm diameter / `0.30` mm drill
- sensor-rail cleanup that moves the `VREG_3V3` via off the PAW3204
  `SENSOR_LED_KIT`/GND pad column, routes the sensor `VDD`/`VDDA` feed down a
  right-side `B.Cu` trunk, and keeps `C1B` tied in with a short local branch
- `TP_LEDKIT` contract cleanup that supersedes the earlier PAW3204 LED test-pad
  move by deleting the non-BOM pad/stub and leaving the PAW3204 LED-kit pin as
  an explicit local no-connect
- U3 VBAT escape cleanup that routes TP4054 BAT around the GND/CHRG pad row
  through an outer dogleg before rejoining the U4 VIN trunk
- C2 input-cap placement cleanup that moves and micro-retargets the 10uF
  capacitor closer to U4 VIN while leaving its GND pad as an honest unconnected
  blocker
- B-side sensor-pocket cleanup that reroutes the `C1B` ground return around the
  PAW3204 LED pad column without moving the shell-bound PAW3204 aperture
- C1A MCU-side decoupler cleanup that moves the non-shell-bound capacitor into
  the U1 `3V3` / `GND1` pocket while leaving the shell-bound `SW1` and U1
  placements fixed
- `TP_VBAT` / right-SW1 cleanup that reroutes `VBAT_SENSE` below the top dome
  ground pad and ties the right `SW1` ring pad into the local U1/C1A ground leg
- SW1 click cleanup that reroutes `CLICK_PRIMARY_N` through a B-side via pair
  instead of through the lower dome ground pad
- C1B/U2 B-side GND cleanup that doglegs around the PAW3204 LED pad column
  without moving the shell-bound sensor aperture
- R1 charger-programming cleanup that moves non-shell-bound `R1` into a
  horizontal pocket and returns its GND pad through the accepted B-side trunk
- U4 regulator-pocket cleanup that nudges non-shell-bound U4 while preserving
  the accepted C2 placement and U3 `VBAT_PROTECTED` dogleg
- D1/NTC ground-return cleanup that moves the local GND leg through a B-side
  dogleg so it no longer shorts the `NTC_SENSE` divider trace
- `TP_VBAT` micro-retarget that moves the sense test pad upward and removes the
  upper `SW1`/`VBAT_SENSE` short
- left-service silkscreen cleanup that moves the dense `J_BAT`, `Q1`, `R8`,
  and `R2A` reference fields to `F.Fab` instead of printing clipped labels over
  the bring-up pads/copper
- `R2A` placement cleanup that moves the CC1 pull-down to `(111.650, 95.000)`
  and retargets its `USB_CC1_RD` plus GND endpoints, clearing the
  `USB_CC1_RD` / `CHARGE_GATE` short without changing ERC, unconnected count,
  or schematic/PCB parity
- `VBAT_SENSE` divider-junction cleanup that retargets the `R7`/`R8`/`TP_VBAT`
  sense trunk through `(113.000, 91.900)`, clearing the upper `SW1` dome-ring
  short without moving shell-bound `SW1` or the CAD dome pocket
- `SW1` / `VBAT_SENSE` topology cleanup that lowers the divider junction to
  `(113.000, 92.100)` and moves the serviceable dome plus shell pocket to
  `(114.200, 95.300)`, reducing total DRC while keeping shorts closed
- top-edge `VBUS_5V` trunk cleanup that retargets the VBUS feed from
  `(105.820, 91.600)` to `(105.600, 91.600)`, clearing the `J_BAT` `MP1`
  short without moving the then-shell-bound battery connector
- in-place `R9` divider flip so the right-side `VBUS_5V` trunk lands on the
  VBUS pad and `VBUS_DETECT` exits the opposite pad into the existing top node,
  plus moving `R9`'s source reference field to `F.Fab` in the copper-dense
  divider pocket
- `SW1` dome-pocket relief that moves the shell-bound click center down to
  `(114.350, 95.780)` and moves the CAD dome pocket with it; this established
  the earlier short-free topology that later ground-continuity and
  three-contact dome-ring closures brought to the current verified
  `DRC=40`, `unconnected=0`, parity `0` snapshot
- non-shell-bound `R11` / `TP_CHRG` relocation down into the charger-status
  pocket at `y=105.000`, shortening the `CHRG_STAT` run and moving their source
  reference fields to `F.Fab` in the dense regulator pocket
- top-edge source-label cleanup that keeps the accepted `VBUS_5V` /
  `VBAT_SENSE` copper after scratch retargets introduced shorting or edge debt,
  and moves the `R7`, `TP_VBAT`, and `SW1` reference fields to `F.Fab`
- charge/regulator-pocket source-label cleanup that keeps the accepted
  `CHARGE_EN`, `VREG_3V3`, and `VBAT_PROTECTED` copper after scratch retargets
  reintroduced shorting or unconnected debt, and moves the `Q2`, `U4`, and `R6`
  reference fields to `F.Fab`
- left-service source-label cleanup that keeps the accepted `USB_CC1_RD`,
  `VBUS_5V`, and `CHARGE_GATE` copper after scratch CC1/gate reroutes
  reintroduced shorting or unconnected drift, and moves the `R4` and `R1`
  reference fields to `F.Fab`
- remaining source-label cleanup that keeps the accepted `NTC_SENSE`,
  `VREG_3V3`, and `CHRG_STAT` copper after scratch reroutes raised total DRC or
  reintroduced shorting, and moves the remaining source-only silkscreen marks
  to `F.Fab`/`B.Fab`
- pad-mask expansion cleanup that keeps `solder_mask_min_width=0.05` but
  changes first-board pad mask expansion from `0.05` to `0`, reducing
  mask-bridge rows without relaxing the minimum mask-web rule
- regulator/C2 spoke-width cleanup that keeps U4 and C2 placement fixed after
  scratch placement variants reintroduced shorts or held total DRC, and narrows
  the two `VBAT_PROTECTED` spokes from `0.32` to `0.24`
- Q1 left-service cleanup that rejects R4 orientation, CC1 dogleg, and
  top-edge `VBUS_5V`/`VBAT_SENSE` variants with unconnected, shorting, or
  copper-edge debt, then nudges Q1 upward by a retained total `0.30` mm and
  retargets its three local service endpoints
- TP_VBAT top power-pocket cleanup that rejects regulator width, R11/TP_CHRG,
  U4, R6, C2 GND, C1A, and layer-hop probes that held total DRC or added debt,
  then nudges `TP_VBAT` right by `0.10` mm and retargets its two local
  `VBAT_SENSE` endpoints
- SENSOR_SCLK MCU-column cleanup that rejects direct SCLK, top-dogleg SCLK,
  `VBUS_DETECT`, and `SENSOR_MOTION_N` route variants with shorts or clearance
  debt, then raises the local SCLK jog from `y=99.900` to `y=99.980`
- TP_MOT MCU-column cleanup that rejects VBUS spine, VBUS dogleg, B-side
  motion-hop, and right-of-VBUS `TP_MOT` variants with dangling vias, shorts,
  mask, or clearance debt, then moves `TP_MOT` to `(121.250, 99.500)` and
  retargets its local `SENSOR_MOTION_N` endpoint
- NTC sense-spine cleanup that rejects USB data-pair and broad `NTC_SENSE`
  trunk/layer-hop variants with shorts, clearance, mask, or track-width debt,
  then moves only the local `NTC_SENSE` junction from `(110.420, 106.700)` to
  `(109.900, 106.700)`
- Left-service CC2 pulldown cleanup that rejects VBUS doglegs, VBUS junction
  moves, and broad R2B shifts with shorts, copper-edge, hole-clearance, mask, or
  extra clearance debt, then moves only `R2B` from `(100.500, 101.500)` to
  `(100.400, 101.500)` and retargets its local `USB_CC2_RD` and GND endpoints
- GND-continuity cleanup that keeps the shell-bound placements and schematic
  contracts intact while closing six unconnected rows: a lower `SW1` local GND
  stitch, via-assisted U3 and C2 returns, a via-assisted `J_BAT` pad-2 return,
  a left-trunk B-side bridge, and a C2-to-U1-side GND return; direct `J1` A12
  and top-`SW1` closure variants were rejected because they reintroduced
  current shorting rows
- `J1` A12 service-ground cleanup that closes the lower USB-C ground row from
  the existing lower GND rail endpoint to the accepted service-edge via while
  leaving the USB-D- fanout intact; top-`SW1` closure remains blocked by the
  latent U4, U1, and Q2 power/sense shorts exposed by direct top-ring closure
- three-contact `SW1` dome-ring cleanup that removes the top ring contact from
  the board and source footprint, keeps the left/right/lower dome contacts, and
  ties the remaining right/lower GND contacts together without reopening shorts
  or courtyard debt
- follow-on scratch-only routing proofs that reject local patch moves after the
  unconnected bucket closed: clearance-only doglegs, placement-level corridor
  moves, local-spine redraws, left-service USB/charge fanout repartitions, and
  right-side regulator/click density moves all failed to beat the retained
  `DRC=40` board without reopening shorting, dangling, or unconnected debt
- clean-room active-R30 lane scratches inside the same packet envelope are also
  rejected for this two-layer pass: all-pad lane sketches returned non-library
  `DRC=560..564`, while safer function-lane sketches still returned
  non-library `DRC=405..416`; none kept `unconnected=0` or the closed shorting
  bucket, so the next reducer is a stackup/envelope architecture decision rather
  than another local route patch
- broad four-layer architecture scratches are rejected as route migrations: a
  KiCad 10-format stackup-only scratch stayed effectively tied with the live
  packet, while inner-layer moves for the existing `VREG_3V3` /
  `VBAT_PROTECTED` diagonals and VREG bus returned non-library `DRC=58..76`
  with reopened unconnected and shorting buckets; the retained four-layer cut is
  narrower, moving only the existing via-to-via `VREG_3V3` support span to
  `In1.Cu`
- placement-level four-layer scratches are rejected while all shell/service
  anchors remain fixed: support-part moves plus retained routes returned
  non-library `DRC=127`, targeted inner-power replacements returned
  non-library `DRC=137`, and full via-per-pad reroutes returned non-library
  `DRC=549..573`; the next reducer must let the service edge, `J1`, `J_BAT`,
  and `SW1` move with shell CAD, or change component classes
- envelope scratches that moved the service edge, `J1`, `J_BAT`, `SW1`, and
  support parts together are also rejected with the current first-board
  BOM/netlist: retained-route variants returned non-library `DRC=149..157`, and
  generated bus reroutes returned non-library `DRC=307..317`; the next reducer
  is a component-class cut, starting with the USB-C service connector or
  off-board charge/program service
- component-class USB service cut that replaces the through-hole-staked USB-C
  receptacle with source-controlled off-board same-net service pads, adds a GND
  continuity via at the former shell-stake return, and moves `USB_CC1_RD` onto
  a B-side jog; KiCad CLI `10.0.2` then reported ERC `0`, DRC `38`,
  unconnected `0`, and schematic parity `0` with no current shorting or
  courtyard bucket
- regulator/input-cap component-class scratches are rejected: same-center `U4`
  pad shrink, `C2` 0402 substitution, tiny same-pin DFN regulator sketches,
  `VREG_3V3` / `VBAT_PROTECTED` route migration, and connected C2 placement
  sweeps did not produce a retainable `DRC<38` board without reopening
  unconnected or shorting debt
- battery-service component-class cut that replaces the onboard JST-SH body
  with source-controlled off-board same-net service pads while preserving
  `VBAT+`, `VBAT-`, `MP1`, and `MP2` parity; KiCad CLI `10.0.2` then reported
  ERC `0`, DRC `36`, unconnected `0`, and schematic parity `0` with no current
  shorting or courtyard bucket
- U4 regulator land-pattern cut that keeps the RT9080 part and pinout, moves
  non-shell-bound `U4` by `(+0.05, -0.05) mm`, and switches only that footprint
  to `PowerFinger_Ring:RT9080_33GJ5_SOT23_5_ServiceClearance`; KiCad CLI
  `10.0.2` then reported ERC `0`, DRC `34`, unconnected `0`, and schematic parity
  `0` with no current shorting or courtyard bucket
- `R8` divider clearance cleanup that moves only non-shell-bound `R8` to
  `(112.100, 93.400)` and retargets its local `VBAT_SENSE`/GND endpoints;
  KiCad CLI `10.0.2` then reported ERC `0`, DRC `33`, unconnected `0`, and
  schematic parity `0` with no current shorting or courtyard bucket
- U4 land-pattern refinement that keeps the RT9080 part, pinout, placement, and
  source-controlled footprint name fixed while shrinking the local pads to
  `0.40 x 0.78 mm`; KiCad CLI `10.0.2` now reports ERC `0`, DRC `32`,
  unconnected `0`, and schematic parity `0` with no current shorting or
  courtyard bucket
- CHRG_STAT fixture-status cut that removes the onboard `R11` pull-up and its
  local `VREG_3V3` spoke while keeping `TP_CHRG` as a fixture-observed
  TP4054 status pad; KiCad CLI `10.0.2` now reports ERC `0`, DRC `31`,
  unconnected `0`, and schematic parity `0` with no current shorting or
  courtyard bucket
- fixture-fed charge-service cut that removes `R4`, `Q2`, `R6`,
  `CHARGE_GATE`, `CHARGE_EN`, and `VBUS_CHG_SW` from this P0, reties U3 `VCC`
  directly to `VBUS_5V` through the non-BOM `Q1` service jumper, marks ESP32-C3
  `GPIO10` no-connect, and moves the local U4 GND via to `(112.000, 102.700)`;
  KiCad CLI `10.0.2` now reports ERC `0`, DRC `27`, unconnected `0`, and
  schematic parity `0` with no current shorting or courtyard bucket
- left-service return-topology cleanup that moves the `R2B` / lower service
  shield GND leg onto B.Cu through a via pair from `(100.880, 101.500)` to
  `(100.650, 104.100)`, clearing the local `VBUS_5V` crossing without moving
  `J1`, `R2A`, `R2B`, `SW1`, the service jumper, or shell CAD anchors; KiCad
  CLI `10.0.2` now reports ERC `0`, DRC `26`, unconnected `0`, and schematic
  parity `0` with no current shorting, dangling, or courtyard bucket
- TP_CHRG endpoint cleanup that moves only the fixture-observed status pad and
  its local `CHRG_STAT` segment from `(116.000, 104.000)` to
  `(109.800, 101.600)`, shortening the charger-status spur beside `U3` without
  adding an onboard pull-up, firmware consumer, shell change, service-anchor
  move, or BOM change; KiCad CLI `10.0.2` now reports ERC `0`, DRC `23`,
  unconnected `0`, and schematic parity `0` with no current shorting, dangling,
  or courtyard bucket
- battery-service `VBAT_PROTECTED` endpoint cleanup that replaces the direct
  `R7`-to-`J_BAT` diagonal with a front-layer dogleg through
  `(107.500, 92.400)` and `(107.500, 95.300)`, keeping `J_BAT`, `R7`/`R8`,
  the service jumper, shell CAD anchors, BOM, and schematic netlist fixed while
  clearing two live crossing rows; KiCad CLI `10.0.2` now reports ERC `0`,
  DRC `21`, unconnected `0`, and schematic parity `0` with no current shorting,
  dangling, hole-clearance, or courtyard bucket
- C1A support-island cleanup that moves the MCU `VREG_3V3` decoupler from
  `(118.450, 94.950)` to `(118.450, 94.700)` and retargets only its local
  `VREG_3V3` / GND endpoints, keeping U1, SW1, J_BAT, the battery-service
  dogleg, shell CAD anchors, BOM, and schematic netlist fixed while clearing
  one live clearance row; KiCad CLI `10.0.2` now reports ERC `0`, DRC `20`,
  unconnected `0`, and schematic parity `0` with no current shorting, dangling,
  hole-clearance, or courtyard bucket
- `VBAT_SENSE` support-corridor cleanup that moves the long ADC leg onto a
  via-assisted B-side escape between `(116.600, 93.250)` and
  `(118.550, 96.850)`, and bends only the local C1A GND return through
  `(119.200, 95.300)` before U1 `GND1`; KiCad CLI `10.0.2` now reports ERC
  `0`, DRC `17`, unconnected `0`, and schematic parity `0` with no current
  shorting, dangling, hole-clearance, or courtyard bucket
- `VREG_3V3` support-corridor cleanup that removes the long front-layer
  U4-to-U1/C1A rail, reuses the existing sensor-rail via at
  `(114.900, 102.900)`, adds one U1-side via at `(118.000, 94.550)`, and lands
  at U1 `3V3` with a short F.Cu hop; KiCad CLI `10.0.2` now reports ERC `0`,
  DRC `15`, unconnected `0`, and schematic parity `0` with no current shorting,
  dangling, hole-clearance, or courtyard bucket
- sensor-LED endpoint-column cleanup that moves only the B-side
  `SENSOR_LED_KIT` return column from `x=115.600` to `x=116.000`, clearing the
  local `VREG_3V3` clearance row while keeping U1, U2, SW1's shell-bound click
  coordinate, C1A, J_BAT, the off-board service anchors, PAW3204 aperture,
  antenna keep-out, active BOM, and schematic netlist fixed; KiCad CLI
  `10.0.2` now reports ERC `0`, DRC `14`, unconnected `0`, and schematic
  parity `0` with no current shorting, dangling, hole-clearance, or courtyard
  bucket
- live `DRC=14` corridor re-probe that keeps the retained board geometry fixed
  after USB data-pair doglegs, U4 GND doglegs, `SENSOR_LED_KIT` column moves,
  and `NTC_SENSE` via/dogleg escapes either tied the current count or reopened
  shorting, extra clearance, solder-mask, dangling, or hole-clearance debt
- `TP_LEDKIT` contract cleanup that removes the non-BOM PAW3204 LED-kit test pad
  and its B-side spur, models U2 pin 5 as an explicit schematic no-connect, and
  keeps U2, the aperture, shell-bound placements, service anchors, charge-service
  jumper, antenna keep-out, active BOM, and schematic/PCB parity fixed; KiCad CLI
  `10.0.2` now reports ERC `0`, DRC `13`, unconnected `0`, and schematic parity
  `0` with no current shorting, dangling, hole-clearance, or courtyard bucket
- four-layer support-span cleanup that adds `In1.Cu` / `In2.Cu` and moves only
  the long via-to-via `VREG_3V3` span from `B.Cu` to `In1.Cu`, keeping the
  fixture-fed charge-service jumper, service anchors, shell-bound placements,
  active BOM, antenna keep-out, and schematic parity fixed; KiCad CLI `10.0.2`
  now reports ERC `0`, DRC `11`, unconnected `0`, and schematic parity `0` with
  no current shorting, dangling, hole-clearance, or courtyard bucket
- USB service-span cleanup that moves only the local `USB_D+` span from
  `(109.200, 105.650)` to `(120.800, 105.650)` onto `In2.Cu` with two
  board-rule vias, keeping `J1`, U1, U4, C2, NTC/R3, shell-bound placements,
  active BOM, antenna keep-out, and schematic parity fixed; KiCad CLI `10.0.2`
  now reports ERC `0`, DRC `10`, unconnected `0`, and schematic parity `0` with
  no current shorting, dangling, hole-clearance, or courtyard bucket
- left-service USB-pair cleanup that reuses the existing `USB_D-` endpoint vias
  and moves only their via-to-via span from `B.Cu` to `In1.Cu`, keeping fixed
  `J1`, D1, U1, service anchors, shell-bound placements, active BOM, antenna
  keep-out, and schematic parity fixed; KiCad CLI `10.0.2` now reports ERC `0`,
  DRC `9`, unconnected `0`, and schematic parity `0` with no current shorting,
  dangling, hole-clearance, track-width, or courtyard bucket
- regulator-corridor layer-partition cleanup that keeps the local
  `NTC_SENSE` divider junction on `F.Cu`, moves its long U1 ADC span to
  `In2.Cu` through two board-rule vias, and moves the existing local `USB_D+`
  service span from `In2.Cu` to `In1.Cu`; KiCad CLI `10.0.2` now reports ERC
  `0`, DRC `6`, unconnected `0`, and schematic parity `0` with no current
  shorting, dangling, hole-clearance, track-width, or courtyard bucket
- U4 VIN/EN topology cleanup that replaces the direct front-layer
  `VBAT_PROTECTED` VIN-to-EN tie through the U4 GND mask pinch with a widened
  right-side dogleg around the GND pad and away from the local `VREG_3V3`
  diagonal; KiCad CLI `10.0.2` now reports ERC `0`, DRC `4`, unconnected `0`,
  and schematic parity `0` with no current shorting, dangling, hole-clearance,
  track-width, solder-mask-bridge, or courtyard bucket
- U4 pad-mask/support-footprint follow-up scratch that is not retained: U4 pad 2
  solder-mask-margin and land-shrink probes tied `DRC=10`, the custom pad-2
  mask/paste aperture raised the live board to `DRC=12`, and the extra-via
  left USB_D- inner-layer hop raised the live board to `DRC=11`; no new copper,
  footprint, or rule change beat the then-retained `DRC=10` state without new
  debt
- remaining left regulator-feed scratch that is not retained: lower
  `VBAT_PROTECTED` doglegs, right-side or lower U4 GND returns, U4 VOUT doglegs,
  upper-junction VREG inner-layer feeds, and small U4 left/right micro-nudges
  all raised the live board to `DRC=5..19` or reopened unconnected, shorting,
  clearance, mask, or inner-span crossing debt; the retained snapshot stays
  ERC `0`, DRC `4`, unconnected `0`, and schematic parity `0`
- remaining two-net layer-partition scratch that is not retained: non-pad U4
  VOUT-to-`In1.Cu` hops, U3 BAT-to-U4 VIN `In1.Cu` hops, and extended
  `VBAT_PROTECTED` service-span inner doglegs either tied the live board at
  DRC `4` without improvement or raised it to DRC `5..7` with shorting,
  clearance, hole-clearance, or retained-inner-span debt
- C2/NTC/R3 support-topology follow-up scratch that is not retained: lower
  `NTC_SENSE` doglegs, offset inner-layer `NTC_SENSE` hops, rotated C2 support
  placement, right-shifted NTC/R3 junctions, and a narrowed C2 VBAT spur either
  raised live DRC to `11..15`, reopened current shorting, or violated the
  `0.20 mm` minimum track-width rule; no geometry beats the retained `DRC=10`
  state
- U4/C2/NTC/R3 micro-placement follow-up scratch that is not retained: isolated
  U4 x/y nudges raised live DRC to `13..14`, a coupled U4+C2/VBAT/GND upward
  retarget raised live DRC to `13`, and a full U4+C2+NTC/R3 upward support
  shift raised live DRC to `15`; no non-shell-bound micro-placement beats the
  retained `DRC=10` state without new mask/clearance pressure
- U4/C2 core scratch that rejects C2-only endpoint moves, C2 pad-size probes,
  coupled U4 VIN/EN/VOUT/GND moves, U4 NC/GND pad refinements, and U4 GND-via
  relocations because the clean variants hold `DRC=20` and the lower-looking
  variants reopen shorting, hole-clearance, unconnected, or extra mask debt
- coupled C2/`NTC_SENSE`/`USB_D+` scratch that rejects the full exposed trade:
  C2-lowered, C2-land-shrink, NTC-junction, local `USB_D+` lane-retarget, and
  via-assisted `NTC_SENSE` variants either tied `DRC=20`, rose to clean
  `DRC=21+`, or reopened shorting; no `DRC<20` topology is retained
- regulator-island VREG/VIN topology cleanup that reroutes U4 VOUT through the
  existing R3/VREG upper lane before dropping to the retained VREG via, then
  shortens the paired U4 VIN/EN `VBAT_PROTECTED` dogleg from `x=115.500` to
  `x=114.250`; the right-shifted VREG-via continuation and lower U4 GND-via
  move were rejected with shorting, hole-clearance, sliver, click, NTC, or
  extra clearance debt, while the retained topology verifies at ERC `0`, DRC
  `3`, unconnected `0`, and schematic parity `0` with no current shorting,
  dangling, hole-clearance, track-width, solder-mask-bridge, or courtyard
  bucket
- C2-node `VBAT_PROTECTED` service-feed cleanup that moves the former long
  front-layer diagonal onto `In1.Cu` through board-rule vias at the C2 VBAT node
  and retained service-feed endpoint; the final retained front bend through
  `(111.200, 103.050)` plus the `In1.Cu` dogleg through
  `(111.000, 105.000)` / `(109.800, 101.000)` clears the two remaining local
  GND-via clearance rows without moving `J1`, `J_BAT`, `SW1`, `U2`, the antenna
  keep-out, or the shell-bound/service anchors; the straight inner span and
  front-layer C2-node diagonal were rejected with shorting, mask, or extra
  clearance debt, while the retained topology verifies at ERC `0`, DRC `0`,
  unconnected `0`, and schematic parity `0` with no current shorting, dangling,
  hole-clearance, track-width, solder-mask-bridge, clearance, crossing, or
  courtyard bucket

This pass cuts the onboard active charge-enable switch from the first P0:
fixture VBUS now feeds TP4054 `VCC` through a non-BOM `Q1` service jumper, and
ESP32-C3 `GPIO10` is intentionally no-connect. The PCB also carries the
recommended sense support parts: `R7`/`R8` = `100k`/`100k` for `VBAT_SENSE` and
`R9`/`R10` = `220k`/`100k` for `VBUS_DETECT`. `VBAT_SENSE` and `VBUS_DETECT`
are routed to the ESP32-C3 resources named in
[INTERFACE-CONTRACT.md](INTERFACE-CONTRACT.md). `CHRG_STAT` remains locally
testable at `TP_CHRG`, but it has no onboard pull-up and no MCU GPIO or
firmware consumer is claimed yet. A fixture must provide a pull-up if charger
status is measured. PAW3204 `SENSOR_NRESET` and `SENSOR_MOTION_N` are likewise
local bring-up pads only for the first optical board, not firmware reset or wake
signals. The `43 x 18 mm` rigid pass now drives the shell CAD fit pass, but it
still does not prove the package is comfortable, printable, RF-clean, or
serviceable with a populated board.

## Mechanical Binding Into CAD

`../cad/r30_oled_none_none_shell_blank.scad` now maps the routed board into the
shell using these KiCad facts:

- board outline: `99..142 x 91..109 mm`, treated as a `43 x 18 mm` PCB around
  center `(120.5, 100)`
- off-board service-pad access: `J1` at `(102.650, 100.000)` on the left
  service edge
- off-board battery service path: `J_BAT` at `(108.600, 94.250)`
- dome pocket: `SW1` at `(114.350, 95.780)`
- optical datum: `U2`/board aperture at `(116.500, 100.000)`
- antenna keep-out: external no-footprint zone from `x=134.150` to board edge

Keep these coordinates in sync if the board moves; the shell should fail loudly
rather than drifting back to anonymous module pockets.

## Hard Constraints

- Treat [PLACEMENT-CONSTRAINTS.md](PLACEMENT-CONSTRAINTS.md) as a blocker list,
  not optional polish.
- Do not substitute the LDO, charge resistor, or battery safety path without
  updating the variant manifest and BOM.
- Do not let convenience routing eat the antenna keep-out.
- Treat the current schematic as first-pass capture with clean local electrical
  and layout gates, not proof that the assembled hardware is validated. The
  current local KiCad CLI `10.0.2` snapshot is ERC=0, DRC=0, unconnected=0, and
  schematic-parity=0.
- Treat the first PCB as a DRC-clean routed board pass, not a completed
  hardware release. Keep ERC/DRC/parity clean through fabrication export and
  physical first-board evidence.
- Close `../FIRST-BOARD-CHECKLIST.md` and `../STACKUP-VERIFY.md` before treating
  this lane as hardware-ready.

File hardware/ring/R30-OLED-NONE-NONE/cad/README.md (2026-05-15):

<!-- SPDX-License-Identifier: CERN-OHL-S-2.0 -->
# R30-OLED-NONE-NONE CAD Skeleton

This directory contains the first editable mechanical source for the active
optical ring lane.

`r30_oled_none_none_shell_blank.scad` is now a parametric lower-shell plus
service-lid packet for the first board. It is still not a production-ready
enclosure, and it does not claim that the fit, comfort, closure hardware, or
focal-distance stack are already validated.

## Inputs Exposed Today

- `finger_circumference_mm`
- `sensor_angle_deg`
- `band_width_mm`
- `shell_height_mm`
- `rim_height_mm`
- `glide_pad_thickness_mm`
- `service_seam_height_mm`
- `export_mode` for either the full shell packet or quick-print fit coupons
- routed `pcb_size_mm`, KiCad-derived feature centers, and antenna keep-out
- lid skirt / seam clearance values
- off-board service-pad access opening and fixture keep-out at the `J1` edge
- board rail, side-stop, and lid compression-pad placeholders
- `SW1` dome pocket and actuator-relief placeholders
- battery, sensor, and module keep-out proxies
- battery harness channel and service-loop relief from the actual `J_BAT`
  service-pad area
- top-access screw-boss placeholders

## What The Model Intentionally Does

- Gives the ring lane a real editable CAD source file in the repo
- Encodes the 30-degree optical-lane posture as a default, not a hard-coded
  forever truth
- Maps the current routed `43 x 18 mm` PCB into a top pod so the mechanical
  story no longer depends on a generic electronics box
- Cuts a first-pass left-edge service-pad access opening and local fixture
  clearance for the routed `J1` service interface
- Adds a non-USB board-retention concept with molded rails, side stop lugs, and
  service-lid compression pads
- Adds a `SW1` dome pocket and actuator relief as a first pass, not as proven
  click ergonomics
- Keeps the structural rim and four discrete glide-pad pockets on the lower
  shell so the focal-distance geometry does not move during service
- Uses a removable top service lid with a locating skirt and pry relief instead
  of pretending the first board can be glue-sealed
- Reserves service volume for the routed board, battery, sensor cavity, and
  service fixture path so stackup conflicts stay visible before fabrication
- Adds a battery harness channel and service-loop relief so the cell has a
  believable removal path from the actual `J_BAT` service-pad area
- Adds quick-print coupon/export modes for the fit unknowns that should be
  checked before spending time on a full shell print

## What Still Needs Real Validation

- Comfort across actual finger sizes
- Real sensor cavity dimensions for the chosen optical sensor and lens kit
- Measured service-fixture access, board rail/stop tolerance, lid pad
  clearance, dome-click travel, battery harness routing, and lid removal
  against a populated board or representative coupons
- Whether two loose service screws are acceptable for limited-dexterity repair
  or need a captured-hardware follow-up
- Battery fit with real wiring, the chosen `BT1` interface, and real connector
  strain relief
- Focal-distance proof on physical surfaces
- Whether the larger top PCB pod is comfortable, accessible, and still inside
  the current `~$9` ring intent once fasteners and printable wall thickness are
  costed

Use [../FIRST-BOARD-CHECKLIST.md](../FIRST-BOARD-CHECKLIST.md) and
[../STACKUP-VERIFY.md](../STACKUP-VERIFY.md) as the active-lane source of truth
for what this CAD needs to prove before secondary variants move forward.

## Current Service Story

- Battery service is top-side only: remove the service screws, lift the lid from
  the pry relief, then lift the cell through the upper opening
- The board service path is also top-side: once the lid is off, molded rails and
  side stops should allow the PCB to lift out without levering on service pads,
  the antenna end, or the dome switch
- The lower shell owns the rim, glide pads, and sensor tunnel so battery
  service does not ask the user or repair tech to disturb the focal-distance
  features first
- The battery path is still an honest first pass until a real replaceable
  harness or fixture, protected cell, and printed lid prove lead bend radius
  and lift clearance

## Quick-Print Fit Coupons

The OpenSCAD file supports these `export_mode` values:

| Mode | Artifact | Fit Unknown Targeted |
|---|---|---|
| `shell` | Full lower shell plus service lid | Whole-packet geometry sanity |
| `service_access_coupon` | Off-board service-pad access pocket | Fixture/pogo access and shell/board loading |
| `board_retention_coupon` | Board rails plus stop lugs | `43 x 18 mm` board slide, lift, and tolerance |
| `lid_pad_coupon` | Board-edge compression-pad channel | Lid pad path without crushing components |
| `battery_harness_coupon` | Harness channel, service-pad access pocket, and service-loop relief | Replaceable harness bend and lift clearance |
| `service_lid_coupon` | Skirt/socket/pry-removal coupon | Reopenable lid handling around service hardware |
| `fit_coupons` | One sheet with all coupons | Fast print for the first fit sweep |

These are validation aids, not new product geometry. A coupon pass should update
[../STACKUP-VERIFY.md](../STACKUP-VERIFY.md) with measured results and leave
`MANIFEST.md` honest if any coupon fails.

## Local Sanity Check

On macOS, prefer installing OpenSCAD with:

```bash
brew install --cask openscad@snapshot
```

The binary is still exposed as `openscad`. A useful packet-level render check is:

```bash
openscad \
  -D 'show_exploded_view=false' \
  -D 'show_reference_solids=false' \
  -D 'show_reference_fasteners=false' \
  -o /tmp/r30_oled_none_none_shell.stl \
  hardware/ring/R30-OLED-NONE-NONE/cad/r30_oled_none_none_shell_blank.scad
```

That command is a geometry sanity check only. It does not prove the shell fits
the real board, battery, or service hardware.

A quick-print coupon sheet can be exported with:

```bash
openscad \
  -D 'export_mode="fit_coupons"' \
  -o /tmp/r30_oled_none_none_fit_coupons.stl \
  hardware/ring/R30-OLED-NONE-NONE/cad/r30_oled_none_none_shell_blank.scad
```

Render an individual coupon by replacing `fit_coupons` with one of the coupon
modes above.

For the durable local first-board coupon bundle, use:

```bash
scripts/generate-r30-ring-fit-coupons.sh
```

That regenerates coupon STLs, preview PNGs, hashes, and a blank physical-check
worksheet under `build/r30-oled-none-none-mechanical/`. The bundle is local
print/preview scaffolding only; transfer measured observations back into
[../STACKUP-VERIFY.md](../STACKUP-VERIFY.md) and
[../MANIFEST.md](../MANIFEST.md) only after physical checks.

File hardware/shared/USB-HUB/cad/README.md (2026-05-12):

<!-- SPDX-License-Identifier: CERN-OHL-S-2.0 -->
# USB-HUB CAD Packet

This directory contains the first editable enclosure source for the active hub
accessory lane.

`usb_hub_enclosure_blank.scad` is now the first mechanical packet for the
stepped direct-plug board in `../kicad/usb_hub.kicad_pcb`. It models a
reopenable top/bottom shell pair, removable service hatch, shell-clamp bosses,
host-fit reference gauges, and quick-print validation coupons. It still does
not claim printed fit, connector strain, or adjacent-port clearance has been
measured.

## Inputs Exposed Today

- PCB envelope; the KiCad pass now uses a stepped `54 x 26 mm` board with a
  USB-A nose widened enough to carry the SOFNG USB-05 shell-tab pads
- `MH1` / `MH2` shell-clamp hole locations copied from the board source
- service window over the `TP1`-`TP9` row plus the `SW1` pad-actuated
  `BOOT_N` service footprint
- rear ESP32-S3 antenna keep-out shown as a plastic-only reference volume
- host insertion shoulder and adjacent-port reference gauges
- quick-print export modes for the USB-A shoulder / adjacent-port coupon,
  `MH1` / `MH2` clamp alignment gauge, and service-hatch reach gauge
- wall thickness and clearances
- top/bottom shell split, removable hatch, and exploded-view spacing

## What The Model Intentionally Does

- Follows the stepped board outline instead of the older rectangular envelope
- Keeps printed shell material from protruding in front of the USB-A host face
- Uses two serviceable clamp points aligned to `MH1` / `MH2`; the intended
  low-cost hardware path is removable small screws or an equivalent reversible
  fastener, not adhesive, heat-shrink, potting, or brass inserts
- Keeps `EN`, `BOOT_N`, UART, power, ground, and trace-inspection pads reachable
  through a removable hatch
- Makes adjacent-port and insertion/removal constraints visible with reference
  gauges instead of treating them as implied pass conditions
- Provides a `host_fit_coupon` mode for cheaply checking the USB-A nose shoulder
  and wider-body adjacent-port envelope before printing the full shell
- Provides a `clamp_alignment_gauge` mode for checking whether `MH1` / `MH2`
  and the printed clamp path line up with the board or board blank
- Provides a `service_hatch_reach_gauge` mode for checking probe/spudger access
  to the service row and removable hatch outline

## What Still Needs Real Validation

- Print fit against a real board or board blank before claiming the shell is
  fabrication-ready
- Confirm `MH1` / `MH2` clamp hardware carries insertion/removal load without
  cracking the printed bosses or bowing the PCB
- Keep the rear ESP32-S3 antenna zone plastic-only; do not add brass inserts,
  metal labels, screws, or copper-backed decoration near the antenna end
- Confirm the service hatch can be opened with a non-marring tool and that the
  pads remain probeable without pulling on the USB connector
- Verify host-port interference with real adjacent USB-A ports; the CAD gauges
  make the constraint explicit but do not prove clearance
- Print the quick coupons and record whether the USB-A shoulder, adjacent-port
  body width, clamp holes, and service hatch reach pass on actual hardware

## Local Sanity Check

Render the full enclosure syntax/manifold check from the repository root:

```sh
openscad -o /tmp/powerfinger-usb-hub-enclosure.stl hardware/shared/USB-HUB/cad/usb_hub_enclosure_blank.scad
```

Regenerate the quick-print validation coupon set, preview PNGs, hash manifest,
OpenSCAD logs, bundle README, and blank physical-check worksheet with:

```sh
scripts/generate-usb-hub-validation-coupons.sh
```

Use [../FIRST-BOARD-CHECKLIST.md](../FIRST-BOARD-CHECKLIST.md) and
[../CONNECTOR-RETENTION-VERIFY.md](../CONNECTOR-RETENTION-VERIFY.md) as the
active-lane source of truth for what this enclosure needs to prove before
secondary hardware moves forward.

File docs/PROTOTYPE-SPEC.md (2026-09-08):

# Prototype Spec — Active Validation Lane

Open-source assistive ring mouse. BLE HID. Full design space and rationale at
the links below — this document is the concise build spec.

- Design matrix: [COMBINATORICS.md](COMBINATORICS.md)
- Click mechanisms: [CLICK-MECHANISMS.md](CLICK-MECHANISMS.md)
- Glide system: [GLIDE-SYSTEM.md](GLIDE-SYSTEM.md)
- IP landscape: [IP-STRATEGY.md](IP-STRATEGY.md)
- First-test parts and purchasing status: [FIRST-TEST-SHOPPING-LIST.md](FIRST-TEST-SHOPPING-LIST.md)

This spec follows the active scope freeze in
[GO-NO-GO-RUBRIC.md](GO-NO-GO-RUBRIC.md): the optical ring pair + hub is the
primary validation lane, the wand is the hedge lane, and everything else is
deferred until the active lane clears Gate 4.

Immediate build scope:

- `R30-OLED-NONE-NONE` optical ring pair
- `USB-HUB`
- `WSTD-BALL-NONE-NONE` wand as hedge-only backup work

Deferred reference builds remain documented below for defensive publication and
later research, not for current execution.

---

## Prototype 1 — Optical Ring Pair (x2 identical units)

| Component | Spec |
|---|---|
| MCU | ESP32-C3-MINI-1 module on custom R30 PCB; bench dev boards listed in the shopping list |
| Sensor | PAW3204DB-TJ3L optical sensor/lens/emitter kit; ADNS-2080 class only as evaluated fallback |
| Click | Metal snap dome (Snaptron SQ-series or equivalent, 5-10M cycles) |
| Battery | LiPo 80-100mAh |
| Charging | Off-board USB service fixture; routed P0 has service pads, no onboard USB-C receptacle |
| Protocol | BLE HID mouse — reports X/Y deltas + click press/release |
| Shell | 3D-printed ring, 30 degree sensor angle, parametric for finger circumference |
| Glide | Raised structural rim (POM or nylon) with replaceable UHMWPE glide pads |
| Focal distance | 2.4-3.2mm, maintained by rim height |
| Sensor cavity | Matte black interior (prevent LED wash-out) |
| BOM target | ~$9 each |

Two identical units. The hub assigns the default roles (cursor + left click on
one, scroll + right click on the other); a companion app may reassign later.
This pair is the first concept-validation lane, not a proven product claim yet.

This is the P0 build. Everything else depends on this working.

---

## Deferred Reference Build — Ball+Hall Ring Pair (x2 identical units)

| Component | Spec |
|---|---|
| MCU | ESP32-C3 SuperMini |
| Sensor | 5mm steel ball in socket, 4 roller spindles with magnets, 4 SMD Hall sensors (DRV5053, power-gated) |
| Click | Metal snap dome |
| Battery | LiPo 80-100mAh |
| Charging | USB-C |
| Protocol | BLE HID mouse |
| Shell | 3D-printed ring, 30 degree sensor angle, parametric for finger circumference |
| Glide | No raised rim needed — ball protrudes below shell, contacts surface directly |
| BOM target | ~$11 each |

Surface-agnostic target: glass, fabric, skin, mirror, and other hard cases.
This prototype exists to validate whether the Hall sensor array can actually
resolve usable cursor deltas from a 5mm ball at finger-pressure force levels.
It is not active implementation scope while the optical ring + hub lane is red.

---

## Deferred Reference Build — Optical Puck Pair (x2 identical units)

| Component | Spec |
|---|---|
| MCU | ESP32-C3 SuperMini |
| Sensor | PAW3204DB-TJ3L optical kit; ADNS-2080 class only after evaluated board-profile changes |
| Click | Metal snap dome (whole-puck press-down, 100–170gf) |
| Battery | LiPo 150–200mAh |
| Charging | USB-C |
| Protocol | BLE HID mouse — reports X/Y deltas + click press/release |
| Shell | 3D-printed disc, 22–28mm diameter, 10–15mm height, concave top |
| Glide | UHMWPE pads on flat bottom (4 discrete pads around sensor aperture) |
| Focal distance | 2.4–3.2mm, maintained by shell floor + pad standoff |
| BOM target | ~$7 each |

Two identical units. Same two-device composition model as the ring pair — the
hub assigns roles (cursor + left click on one, scroll + right click on the
other). The puck validates the keyboard-coexistent form factor: can users
productively alternate between typing and fingertip pointing on desktop pucks?
This is deferred until the active ring + hub lane clears Gate 4.

Key design differences from the ring:
- **Rigid PCB** (not flex/rigid-flex) — cheaper, more reliable, simpler layout
- **Non-parametric shell** — one size fits all hands, no finger circumference
- **Larger battery** — weight budget relaxed since the puck is not worn
- **Press-down click** — entire top surface is the actuator

See [POWERPUCK-SPEC.md](POWERPUCK-SPEC.md) for the full design specification.

---

## Hedge Lane — Ball+Hall Wand (x1)

| Component | Spec |
|---|---|
| MCU | ESP32-C3 SuperMini |
| Sensor | Ball+Hall at tip (same mechanism as Prototype 2) |
| Click | Kailh GM8.0 micro switch on barrel, thumb-operated |
| Body | Aluminum or stainless steel tube, ~8mm diameter x 120mm length |
| Battery | LiPo 100-150mAh |
| Charging | USB-C |
| Protocol | BLE HID mouse |
| BOM target | ~$14 |

Pen-grip hedge lane. The ball at the tip must accommodate 30–70 degree pen
angles from horizontal. The ball+Hall sensor is intended to be angle-independent
and surface-flexible, unlike optical pen mice that fail past ~20 degrees, but
those claims remain hypotheses until bench testing is complete. See
[WAND-COMPETITIVE.md](WAND-COMPETITIVE.md) for the full competitive analysis.

---

## Active Accessory — USB Hub Dongle (x1)

| Component | Spec |
|---|---|
| MCU | ESP32-S3 (BLE 5.0 + native USB OTG) |
| Role | BLE central for the active ring pair first, with future-safe room for other PowerFinger devices later |
| Output | USB HID mouse — single unified mouse to the host OS |
| Connector | USB-A or USB-C |
| Enclosure | 3D-printed, small USB-stick form factor |
| BOM target | ~$5-6 |

The hub is the intended P0 composition path: it pairs with the active optical
ring pair first, assigns roles (first ring = cursor + left click, second =
scroll + right click), composes their events into a single USB HID mouse
report, and presents to the OS as one mouse. No host-side remapping software is
required if this path validates cleanly.

A single ring also works without the hub — pairs directly with the host as a
standard BLE HID mouse for basic cursor + click.

---

## Fixed Across All Devices

- **Ring/wand MCU:** ESP32-C3 (BLE 5.0, supports 7.5ms connection intervals,
  ESP-IDF framework)
- **Hub MCU:** ESP32-S3 (BLE 5.0 central + USB OTG device)
- **Protocol:** Each ring is a BLE HID mouse peripheral. The hub is a BLE
  central + USB HID device. Single ring works standalone (BLE HID to host).
  Multi-ring works through the hub (BLE to hub, USB to host).
- **License:** MIT firmware, CERN-OHL-S 2.0 hardware (open source, your name on
  it if you want it)
- **No cloud dependency.** No app required for single-ring or multi-ring
  function. Companion app is optional configuration UI.
- **No planned obsolescence.** Every component must be replaceable. Commodity
  parts with multiple source vendors

---

## What We Need From You

- **Schematic + PCB layout** — flex or rigid-flex for ring, rigid for hub, and
  rigid for wand only if the hedge lane is deliberately activated
- **Ring shell CAD** — parametric for finger circumference and sensor angle.
  OpenSCAD, FreeCAD, or Fusion 360. Should accept at minimum: `finger_circumference`
  (mm) and `angle` (degrees)
- **Hub enclosure CAD** — reopenable small USB-stick form factor with connector
  reinforcement and service access
- **Wand body CAD** — tube with internal component mounting
- **Assembled prototypes** — build the optical ring pair + hub first; touch the
  wand only as hedge work once that priority is explicit
- **Firmware is handled separately.** Hardware work should preserve bring-up,
  flashing, battery-safety, and native-USB access for the repo firmware rather
  than assuming a stock example is the final validation path

### Scope

Immediate scope is the optical ring pair + hub. The wand remains available as a
hedge path, but it is not a second primary program. Puck, secondary ring, Pro,
and OCR-adjacent work remain deferred until the active lane clears Gate 4.

---

## Constraints That Matter

These are non-negotiable — see CLAUDE.md and the design docs for full rationale.

- **LDO: RT9080-33GJ5** (not AP2112K). 0.5µA quiescent vs 55µA — the LDO
  dominates deep sleep power. See [POWER-BUDGET.md](POWER-BUDGET.md).
- **Charge resistor: 20kΩ** (not 2kΩ or 10kΩ). Sets 50mA charge rate (0.625C on
  80mAh). 10kΩ (100mA) produces unsafe temperatures in the sealed ring enclosure
  — see [BATTERY-SAFETY.md](BATTERY-SAFETY.md) §5 thermal analysis.
- **Hall sensor: DRV5053** (not SS49E). ~3mA vs 6mA per sensor. Must be
  power-gated via MOSFET in sleep.
- **BOM ceiling:** No single variant may exceed $25. The cheapest ring must stay
  under $10.
- **BLE HID latency < 20ms.** Default 15ms connection interval with adaptive
  switch to 7.5ms during active tracking.
- **Ring height budget: ~10mm** finger-to-surface. Sensor + PCB + battery must
  fit in ~7-8mm above surface with 2.5-3mm air gap below.
- **DPI/sensitivity must be configurable** via BLE characteristic, never
  hard-coded.
- **Ring geometry must be parametric** for finger size — never assume a specific
  hand.
- **Sourcing honesty:** Prefer multi-source components. Any single-source
  prototype part must be called out with its accepted risk and evaluated
  fallback path before outreach or fabrication quoting.

---

## Battery Safety

Full analysis: [BATTERY-SAFETY.md](BATTERY-SAFETY.md)

### Cell specification

All LiPo cells **must have an integrated protection circuit module (PCM)**
providing overcharge (4.25-4.30V), over-discharge (2.4-2.5V), and short-circuit
protection. Bare/unprotected cells are rejected regardless of cost savings. Cells
must have UN 38.3 test documentation from the manufacturer.

### Charge rate constraint

**RPROG must be 20 kohm (not 10 kohm).** This sets 50 mA charge current (0.5C
on 100mAh, 0.625C on 80mAh). The ring is a sealed enclosure worn on skin with
no ventilation. At 100 mA (RPROG = 10 kohm), the TP4054 dissipates up to 200 mW,
which in the ring's thermal environment produces an estimated 50 deg C
temperature rise above body temperature — reaching ~87 deg C internally.
This exceeds both the cell's 45 deg C charge limit and IEC 62368-1's 48 deg C
skin contact limit (Clause 9.1.2, Table 42, non-metal continuous contact).

At 50 mA the worst-case temperature rise drops to ~25 deg C. Charge time
increases from ~1 hour to ~2 hours — acceptable for a device charged overnight.

### Thermal limits

| Limit | Value | Source |
|---|---|---|
| Max skin-contact surface temperature | 48 deg C | IEC 62368-1 Table 42 (non-metal, continuous) |
| Max cell charging temperature | 45 deg C | Cell manufacturer spec (typical LiPo) |
| Min cell charging temperature | 0 deg C | Below this, lithium plating occurs |

### Hardware additions for safety

| Component | Purpose | BOM impact |
|---|---|---|
| NTC 10k B3950 (0402) + divider resistor | Cell temperature monitoring via ADC | +$0.03 |
| SI2301 P-ch MOSFET (SOT-23) + 2N7002-class gate driver/bias passives | Firmware charge enable/disable on VBUS without exposing the MCU to the 5 V gate pull-up | +$0.07 |
| RPROG change: 10 kohm to 20 kohm | Reduce charge current from 100 mA to 50 mA | $0.00 |

The TP4054 has **no NTC input and no temperature monitoring**. The firmware must
fill this gap using the NTC thermistor and a logic-safe VBUS MOSFET gate path.

### Firmware requirements

- **Temperature monitoring during charging:** Read NTC via ADC. Disable charging
  (cut VBUS via MOSFET) at T >= 45 deg C. Re-enable at T < 40 deg C (5 deg C
  hysteresis). Disable charging at T < 0 deg C.
- **Overvoltage detection:** If VBAT > 4.25V, disable charging. This indicates
  a TP4054 fault or cell PCM failure.
- **Critical low voltage:** If VBAT < 3.0V, enter deep sleep immediately
  (existing 3.2V cutoff handles the normal case).
- **Charge state tracking:** Detect USB via VBUS GPIO; monitor TP4054 CHRG pin.
  Stay awake during charging to maintain temperature monitoring.
- **Cell health logging:** Track charge cycles, max temperature, and fault
  events in NVS. Expose via BLE diagnostic characteristic.

### Shell requirements

- **Non-hermetic closure.** Friction-fit or snap-fit that separates under
  internal pressure. A sealed shell could build pressure during a cell vent
  event.
- **Minimum 1.0mm wall thickness** over the cell for mechanical puncture
  protection.
- **Swelling detection.** Cell swelling must be tactilely or visually detectable
  through the shell.

---

## Build Order

| Priority | What | Quantity | Why |
|---|---|---|-----|
| **P0** | Optical ring pair (Prototype 1) | x2 | Validates core concept: two identical rings = mouse |
| **P0** | USB hub dongle | x1 | Validates multi-device composition — two devices = one USB mouse |
| **P1** | Optical puck pair (Prototype 3) | x2 | Validates keyboard-coexistent desktop form factor |
| **P1** | Ball+Hall ring pair (Prototype 2) | x2 | Validates surface-agnostic sensing in ring form factor |
| **P1** | Ball+Hall wand (Prototype 4) | x1 | Validates pen-on-any-surface concept |

P0 is the gate. If the optical ring pair works as a mouse through the hub,
everything else follows. The hub is P0 because multi-device composition is the
core product concept — without it, you just have two independent mice. The puck
pair at P1 is the cheapest prototype (~$7 each) and validates whether the
typing↔pointing workflow works without wearing a ring.

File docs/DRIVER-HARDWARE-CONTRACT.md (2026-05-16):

<!-- SPDX-License-Identifier: MIT -->
# Active-Lane Driver/Hardware Contract

This document records the minimum contract between the current firmware drivers
and the active hardware packets. Its purpose is narrow: keep software bring-up
honest even while CAD, board placement, and first-board routing are still moving.

The firmware architecture is mostly stable across mechanical changes. The ring
runtime reads a small sensor interface, applies calibration and click
suppression, then emits HID reports. The hub runtime accepts ring reports,
applies roles, and emits one USB HID mouse. CAD can change around that shape.
Electrical semantics, focal geometry, battery safety, and RF behavior cannot.

## Scope

- Active validation lane: `R30-OLED-NONE-NONE` ring pair plus `USB-HUB`
- Hedge lane: `WSTD-BALL-NONE-NONE` only where it clarifies deferred risk
- Deferred here: ball+Hall ring, Pro optical-on-ball ring, puck, IMU, OCR,
  direct companion mode, packaged apps, and broader gesture expansion

This file does not replace packet-level hardware contracts. The ring packet's
local net map remains
[`hardware/ring/R30-OLED-NONE-NONE/kicad/INTERFACE-CONTRACT.md`](../hardware/ring/R30-OLED-NONE-NONE/kicad/INTERFACE-CONTRACT.md).
The active board firmware binding is
[`R30-OLED-FIRMWARE-CONFIG.md`](R30-OLED-FIRMWARE-CONFIG.md). This file maps
those hardware facts back to firmware behavior and gate impact.

## Classification

| Classification | Meaning | Required action |
| --- | --- | --- |
| Driver-stable | The part may move or the shell may change while the same firmware seam still applies. | Preserve the signal type, voltage domain, pin contract, and report shape. |
| Board-contract change | The signal semantics, pin allocation, Kconfig value, voltage level, or report format changes. | Update firmware config, packet contract docs, and focused tests together. |
| Concept-risk item | Firmware can run, but physics may still make the product unusable. | Treat bench or human-loop evidence as the gate, not a green build. |
| No-go candidate | If the item fails, the active lane must pause or change architecture. | Escalate to BDFL decision with a recommended fallback. |

## Ring Contract

| Hardware surface | Firmware seam | Required hardware contract | Missing or degraded behavior | Gate impact |
| --- | --- | --- | --- | --- |
| ESP32-C3 ring MCU, flash, NVS, BLE radio | `firmware/ring/main`, `pf_hal`, `ble_hid` | ESP32-C3-compatible module with enough flash for the ring app, working NVS, BLE HID support, stable reset/boot, and antenna keep-out preserved. | No meaningful fallback. A dev board can prove firmware, but a custom ring with broken boot, NVS, or RF is not a ring proof. | Blocks Gate 1 and Gate 3. |
| PAW3204-class optical sensor IC | `CONFIG_SENSOR_PAW3204`, `sensor_paw3204.c` | `SENSOR_SCLK` and `SENSOR_SDIO` must match Kconfig, run at the sensor's logic level, and reach a real PAW3204-compatible sensor that returns the expected product ID, deltas, motion, and SQUAL-like confidence. | Runtime disables motion and can remain click-only. That is useful diagnostics, not a successful ring mouse. | Blocks Gate 1. |
| PAW3204 `SENSOR_NRESET` / `SENSOR_MOTION_N` pads | No production consumer in the active packet | First optical board keeps both nets as local bench pads. Firmware polls the sensor over `SENSOR_SCLK`/`SENSOR_SDIO` and uses the dome as the only configured deep-sleep GPIO wake source. | No sensor-reset GPIO and no optical motion wake on P0. If bench evidence shows polling cannot recover or dome-only wake is unacceptable, allocating either line is a board-contract change. | Not a current gate blocker. |
| PAW3204 lens, emitter, aperture, glide/focal stack | Same PAW3204 driver, plus `SURFACE-TEST-PROTOCOL.md` evidence | Matched lens/emitter kit, matte cavity, aperture alignment, and 2.4-3.2 mm working focal distance under realistic pressure and click force. | Driver may return plausible bytes while the human loop fails through dropout, jitter, or click displacement. | Blocks Gate 1 and Gate 2. |
| Primary snap dome | `CONFIG_CLICK_SNAP_DOME`, `click_dome.c`, dead-zone logic | Dome shorts the configured GPIO to ground when pressed, supports internal pull-up, raises both edges, and is mechanically placed so pressing does not rotate the ring off target. | Firmware can disable buttons if init fails. If it works electrically but shifts the ring, software filtering cannot rescue the click loop. | Blocks Gate 1. |
| VBAT sense divider | `CONFIG_POWERFINGER_VBAT_ADC_CHANNEL`, `power_manager.c`, diagnostics | Divider must scale protected cell voltage into ADC range, stay tied to the Kconfig ADC channel, and be present on any board claiming low-voltage cutoff or battery diagnostics. | ADC init/read failure drives safety fallback toward shutdown. A board with no configured divider must not claim battery safety behavior. | Blocks Gate 3. |
| Cell NTC sense | `CONFIG_POWERFINGER_NTC_ADC_CHANNEL`, thermal policy | NTC must measure cell temperature, not convenient board ambient. Kconfig must name the populated ADC channel for any board claiming thermal charge cutoff. | If omitted or disabled, firmware cannot protect the cell from TP4054's missing NTC input. | Blocks Gate 3 for wearable charging claims. |
| Charge-enable MOSFET path | `CONFIG_POWERFINGER_CHARGE_ENABLE_PIN`, `power_manager.c` | Boards that claim firmware charge cutoff need a GPIO-controlled logic-safe gate path. The R30 P0 board pass sets this Kconfig value to `-1` because fixture VBUS feeds TP4054 `VCC` through the non-BOM service jumper. | If unpopulated or Kconfig-disabled, charging may still occur electrically, but firmware charge cutoff is not present. | Blocks Gate 3 for enclosure charging. |
| VBUS detect | `CONFIG_POWERFINGER_VBUS_DETECT_PIN`, low-battery wake/charge policy | Resistor-divided VBUS presence must reach the configured GPIO and read false when unplugged. | Firmware cannot distinguish charge-present recovery from battery-only lockout. Do not claim USB-wake or charge-state behavior. | Blocks Gate 3 edge cases. |
| `CHRG_STAT` pull-up/status pad | No production consumer in the active packet | Local status pad may exist for hardware test, but no ring firmware behavior depends on it today. | Safe to omit from firmware claims. Adding a firmware consumer is a board-contract change. | Not a current gate blocker. |
| USB-C charge/service connector | Flashing, charge path, bring-up access | Connector must be mechanically retained, provide the intended charge/service access, and preserve reopenable battery service. | Firmware can be correct while the device is unserviceable or unsafe to charge. | Blocks Gate 2 and Gate 3. |
| Protected harnessed LiPo | Power manager, battery safety docs | Cell must fit the shell, have integrated PCM, have a replaceable harness path, and meet the published safety procurement requirements. | No software workaround for an unprotected, non-serviceable, or unfittable cell. | No-go candidate for the ring form factor. |
| RF/antenna keep-out | BLE HID and hub/single-host link | Module antenna keep-out and body-worn orientation must preserve a stable low-power BLE link. | Firmware may pass host tests while the physical ring drops or needs unacceptable TX power. | Blocks Gate 3. |

## Hub Contract

| Hardware surface | Firmware seam | Required hardware contract | Missing or degraded behavior | Gate impact |
| --- | --- | --- | --- | --- |
| ESP32-S3 hub MCU | `firmware/hub/main`, `ble_central`, TinyUSB | ESP32-S3-compatible module with native USB device support, BLE central support, NVS, enough flash, and preserved antenna keep-out. | No meaningful fallback for the active hub lane. | Blocks Gate 4. |
| USB power and 3.3 V rail | `usb_hid_mouse_init`, BLE central runtime | On-board regulation must provide stable 3.3 V from USB VBUS, with local decoupling and no dev-board-only power assumption. | Firmware init failures or intermittent USB/BLE behavior become expected. | Blocks Gate 4. |
| USB connector and ESD entry | TinyUSB HID report path | D+/D-, VBUS, ground, connector orientation, shell retention, and ESD protection must match the USB-HUB packet. | Host may never enumerate, or mechanical insertion may damage the board. | Blocks Gate 4. |
| Ring BLE report ingest | `hub_ring_report_t`, `ble_central`, `event_composer_feed` | Rings must present the expected HID/report characteristics and stable ring indices. Reports are `{buttons, dx, dy, wheel}` with signed 8-bit motion fields. | Composer ignores disconnected or stale slots, but a report-shape mismatch breaks composition. | Blocks Gate 4. |
| Role persistence | `role_engine.c`, `hal_storage` | NVS must persist MAC-to-role assignments without blocking the USB HID loop. | Runtime defaults may work in a session, but reconnect role stability is not proved. | Blocks Gate 4 reconnect criteria. |
| Event composition output | `event_composer.c`, `usb_hid_mouse.c` | USB host must see one standard HID mouse. Disconnect paths must always release button state and zero stale deltas. | Stuck buttons or stale role state are accessibility hazards, not acceptable rough edges. | Blocks Gate 4. |
| Companion CDC control surface | `companion_cdc`, `companion_protocol` | CDC may expose settings/diagnostics, but the active mouse workflow must not require a packaged app or cloud dependency. | CDC failure is serious for configuration, but not a valid reason to make host-side software mandatory. | Supports Gate 4; does not replace HID proof. |

## Deferred Driver Risks

| Deferred component | Firmware status | Why it is deferred |
| --- | --- | --- |
| Ball+Hall ring or wand | The ADC driver shape is clear: four Hall channels, baseline capture, differential X/Y, and Hall power gating. | The risky part is not the C driver. It is the ball, roller, magnet, friction, cleaning, and signal linearity at usable force. |
| PMW3360 optical-on-ball | SPI driver shape is clear, including SROM upload and burst reads. | The checked-in SROM blob is a placeholder; the sensor also adds rails, lens geometry, current draw, and possible level-shift or out-of-spec VDDIO questions. |
| ADNS-2080 or another PAW3204 fallback | Treat as a real substitution, not a free BOM swap. | A fallback optical sensor may preserve the product concept, but it can change protocol, timing, lens, footprint, and surface behavior. |
| Piezo plus LRA click | Click interface can support another implementation. | It changes wake behavior, haptic suppression, power spikes, and mechanical coupling into the optical sensor. |

## Bring-Up Rules

1. If a driver init fails, first classify whether the failure is a driver bug,
   board-contract mismatch, or missing physical evidence. Do not immediately
   tune filters around a mechanical or optical failure.
2. Do not claim Gate 1 from host tests alone. Gate 1 requires a real single-ring
   human control loop on the surface protocol.
3. Do not claim Gate 3 charge safety unless `VBAT_SENSE`, NTC, charge enable,
   and VBUS detect are wired, Kconfig-enabled, and observed on the actual board.
4. Do not claim `CHRG_STAT`, PAW3204 reset, or PAW3204 motion-wake firmware
   behavior until production firmware symbols consume them and tests cover them.
5. If a pin assignment changes, update the packet-level interface contract,
   Kconfig fragment or board config, and host tests in the same patch.
6. If a component is replaced by an alternate, re-check the driver protocol,
   voltage domain, package, lens/mechanical interface, and BOM ceiling before
   calling it compatible.
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

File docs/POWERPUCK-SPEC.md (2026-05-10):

# PowerPuck Specification — Desktop Fingertip Mouse

Two small disc-shaped BLE HID mice that rest on a desk surface, operated by
placing fingertips on top and sliding. The PowerPuck resolves the ring form
factor's fundamental keyboard-coexistence problem: the user lifts their fingers
to type, places them back to point. No donning, no doffing, no mode switch.

**Form factor prefix:** P (design-space matrix)
**Product name:** PowerPuck
**Firmware path:** `firmware/puck/`
**Kconfig:** `POWERFINGER_FORM_FACTOR=PUCK`

---

## Why This Form Factor Exists

The fingertip ring (R-00 through R-45) requires the user to either remove the
ring or lift the finger away from the keyboard to type. The nail mount (N-30,
N-45) is the only keyboard-compatible ring variant, and it remains at concept
stage with extreme height constraints (≤3–4mm above nail). Every other ring
variant imposes a mode switch penalty on every typing↔pointing transition.
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

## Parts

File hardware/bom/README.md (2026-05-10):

<!-- SPDX-License-Identifier: CERN-OHL-S-2.0 -->
# Bills of Materials

Pre-schematic BOMs for P0 and P1 prototype variants. These are intent documents
— they specify target components and acceptable alternatives. When KiCad
schematics exist, the EE generates authoritative BOMs from the schematic and
these files become reference.

## Files

| File | Variant | BOM Target | Priority |
|---|---|---|---|
| `R30-OLED-NONE-NONE.csv` | Optical ring (30°, dome click) | ~$9 | P0 |
| `R30-BALL-NONE-NONE.csv` | Ball+Hall ring (30°, dome click) | ~$11 | P1 |
| `WSTD-BALL-NONE-NONE.csv` | Ball+Hall wand (standard tip) | ~$14 | P1 |
| `USB-HUB.csv` | USB hub dongle (BLE central + USB HID) | ~$5–6 | P0 |

Matching publication packets live under:

- `hardware/ring/R30-OLED-NONE-NONE/`
- `hardware/ring/R30-BALL-NONE-NONE/`
- `hardware/wand/WSTD-BALL-NONE-NONE/`
- `hardware/shared/USB-HUB/`

## Format

Standard CSV. Columns follow OSHWA/KiCad convention:

`Ref, Qty, Description, Value, Package, Manufacturer, MPN, Supplier, Supplier PN, Unit Cost, Notes`

- **Unit Cost** is at prototype quantities (1–10 units), not volume pricing.
- **Notes** column lists acceptable alternatives and constraints.
- Supplier part numbers are provided where known; `—` means "search by MPN."
- Prefer multi-source components. Any single-source prototype part must be
  explicitly flagged with its accepted risk and evaluated fallback path; do not
  call the BOM multi-source until that is true.
- Battery line items must meet [BATTERY-SAFETY.md](../../docs/BATTERY-SAFETY.md):
  integrated PCM, UN 38.3 documentation, and no harvested cells.

## Suppliers Referenced

| Supplier | URL | Notes |
|---|-----|---|
| LCSC | https://lcsc.com | Best for SMD components, ships from China |
| DigiKey | https://digikey.com | US/EU stock, fast shipping, higher prices |
| Mouser | https://mouser.com | Similar to DigiKey |
| AliExpress | https://aliexpress.com | Cheapest for modules, sensors, batteries. Slow shipping. |
| McMaster-Carr | https://mcmaster.com | Raw materials (UHMWPE sheet, metal tube, steel balls) |
| JLCPCB | https://jlcpcb.com | PCB fabrication + assembly |
| PCBWay | https://pcbway.com | PCB fabrication, good for flex PCB |

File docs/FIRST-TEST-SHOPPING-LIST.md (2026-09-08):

<!-- SPDX-License-Identifier: MIT -->
# First-test shopping list

Refreshed 2026-09-07. USD, US suppliers, before shipping and tax. Listed prices
were checked on that date; stock must be reconfirmed at checkout. Consumable
allowances below are planning estimates, not vendor quotes.

Scope: two optical ring nodes plus one USB hub, following the
[active lane](ACTIVE-LANE-CHECKLIST.md). Start with one node, then add the second.
Development boards support USB-powered BLE/USB bench tests; optical control and
wearable qualification also require the sensor kit and physical ring fixture.

## Buy or reuse for the first bench

| Qty | Item | Price / allowance | Purpose and purchasing status |
| --- | --- | --- | --- |
| 2 | [Espressif ESP32-C3-DEVKITM-1-N4X](https://www.digikey.com/en/products/detail/espressif-systems/ESP32-C3-DEVKITM-1-N4X/25587617) | $8 each; **$16 total** | Two ring-node controllers; listed in stock. Documented headers and Micro-B USB. |
| 1 | [ESP32-S3-DevKitC-1-N8R8, Adafruit 5336](https://www.adafruit.com/product/5336) | **$19.95** | Hub controller, onboard antenna, native USB plus separate UART USB. Listing offers Add to Cart; no stock count provided. |
| 4 | USB data cables, host connector to Micro-B | $12–20 total allowance | Two C3 boards, S3 native USB, and S3 debug UART. Reuse a compatible host hub/adapter if necessary. |
| 1 set | Two breadboards, short jumper wires, two normally-open momentary buttons, resistor/capacitor assortment | $25–40 allowance | Stable bench wiring and click inputs; final resistor values follow the bench wiring plan. |
| 1 | Digital multimeter | Reuse/borrow; otherwise $25–50 allowance | Continuity and supply checks before connection. |
| 3 kits | PAW3204DB-TJ3L sensor with matched lens and emitter | **Quote required** | Two working optical nodes plus one spare. Exact low-quantity complete-kit supply remains unresolved. |

Boards total **$35.95**. With cables and wiring, allow **about $75–100**, assuming
an existing multimeter and host computer. Allow **about $100–150** if a meter is
also needed. Both totals exclude optical kits, printed fixtures, instruments,
shipping and tax.

For the optical quote, specify **PAW3204DB-TJ3L** and ask the supplier to confirm
the complete illumination/lens stack, pinout, supply requirements, dimensions,
minimum order and unit price. The
[manufacturer datasheet hosted by EPS Global](https://www.epsglobal.com/Media-Library/EPSGlobal/Products/files/pixart/PAW3204DB-TJ3L.pdf?ext=.pdf)
identifies the PNLR-012LSI infrared LED lens. Confirm what the kit actually
includes before ordering. The old sensor prices in the
[reference BOM](../hardware/bom/R30-OLED-NONE-NONE.csv) are estimates, not a
verified purchasing route. Other PAW3204 suffixes, generic mouse controller ICs,
ADNS-2080 and PMW3360 require hardware/driver evaluation before substitution.

## Buy or borrow for measurement

| Qty | Item | Checked price | When needed |
| --- | --- | --- | --- |
| 1 | [Nordic PPK2, Adafruit 5048](https://www.adafruit.com/product/5048) | **$99.95**, listed in stock | Active/idle/sleep current qualification. Micro-B cable is extra; reuse one or add a fifth cable. |
| 1 | [SparkFun 8-channel 24 MHz USB logic analyzer, TOL-18627](https://www.sparkfun.com/usb-logic-analyzer-24mhz-8-channel.html) | **$26.95** | Sensor bus and GPIO timing, using PulseView/sigrok. Listing shows conflicting stock/backorder labels; confirm availability or borrow equivalent. USB-C cable and jumper leads included. |
| 1 optional | [Nordic nRF52840 Dongle](https://www.digikey.com/en/products/detail/nordic-semiconductor-asa/NRF52840-DONGLE/9491124) | $11.02, **out of stock at this supplier** | BLE packet diagnosis with [Nordic's sniffer](https://www.nordicsemi.com/Products/Development-tools/nRF-Sniffer-for-Bluetooth-LE). Borrow or locate stock when RF diagnosis needs it. |

PPK2 plus analyzer adds **$126.90**: roughly **$200–225** for the bench and these
two instruments, still excluding sensors/fixtures and assuming a reused meter.
Check the analyzer vendor's ground-pin erratum: the pin next to input 6 may
carry a clock; use a verified ground pin.

Borrow a current-limited supply and contact thermometer for custom-board and
charging bring-up. Keep the USB and profiler power paths explicitly isolated
when powering a DUT from the profiler. Dev-board LEDs, regulator and USB bridge
contribute current; product power claims require an isolated DUT measurement.
GPIO captures and phone video alone do not establish sensor-to-host latency
below 20 ms; that requires a defined, synchronized measurement procedure.

## Gather for optical and accessibility tests

- Wood, glass, fabric, paper, glossy magazine and matte plastic samples.
- A 300 mm ruler, 150 mm digital calipers, tape and marker.
- A phone capable of high-frame-rate video and a stable clamp; reuse equipment.
- A 0.1 g scale and 50/100/200 g test weights for repeatable fixture loading.
- Small samples of 5 mm snap domes around 150/200/250 gf and 0.5 mm UHMWPE glide
  material. Compare click force with users' needs; a bench button does not
  qualify ring ergonomics.
- Printed ring and hub fit coupons, using an existing printer or print service.
  Allow $30–60 for a small fit/consumables batch if basic measuring tools are
  already available; obtain a print quote before treating this as a firm cost.

Use [the surface protocol](SURFACE-TEST-PROTOCOL.md) for measured outcomes,
including surfaces on which optical tracking fails. Generate coupons through
`scripts/generate-r30-ring-fit-coupons.sh` and
`scripts/generate-usb-hub-validation-coupons.sh`; record physical observations in
the existing ring and hub coupon ledgers.

## Resolve before flashing or ordering custom boards

1. **Create a reviewed bench pin profile and wiring sheet.** The C3 DevKitM-1
   [uses GPIO8 for its RGB LED](https://documentation.espressif.com/esp-dev-kits/en/latest/esp32c3/esp32-c3-devkitm-1/index.html),
   while the custom R30 profile uses that pin for the dome. Supply/battery/NTC
   sense inputs also need deliberate bench treatment. Do not flash the custom
   R30 profile unchanged onto the dev board with floating sense inputs. A
   SENSOR_NONE/simulated-input harness can exercise protocol behavior while
   optical sourcing is open; human-control qualification needs the real sensor.
2. **Use the S3 native USB port for HID/CDC.** Its UART bridge port is for
   flashing/debugging. Identify both ports and the received board revision in
   the wiring sheet before testing.
3. **Close fit and supplier intake before assembly purchase.** Follow the
   [ring first-board checklist](../hardware/ring/R30-OLED-NONE-NONE/FIRST-BOARD-CHECKLIST.md)
   and [hub first-board checklist](../hardware/shared/USB-HUB/FIRST-BOARD-CHECKLIST.md).
   Request a quote for two assembled rings and one hub, with spare-board pricing
   separately. Derive the assembly order from the current CAD packet;
   [reference CSV BOMs](../hardware/bom/README.md) are not assembly authority.
4. **Select batteries after measured fit and harness definition.** The ring
   calls for protected 80–100 mAh 3.7 V cells, target maximum 20 × 15 × 4 mm,
   documentation and replaceable harnesses per the reference BOM. Match charge
   current to the selected cell under [battery safety](BATTERY-SAFETY.md).
   The routed P0 uses off-board USB/battery service pads and fixture-controlled
   charge VBUS; it has no onboard USB-C receptacle or MCU charge cutoff.

Bench equipment is a reusable development expense. The ring's roughly $9 BOM
target and the project ceilings still need validation against actual component
and assembly quotes; this shopping list does not establish those costs.

## Recommended follow-up

Prepare the dedicated C3/S3 bench profiles, connector-labelled wiring sheet,
and local bring-up record; prepare an exact sensor-kit RFQ for review. Acceptance:
the pin and sense-input audit passes, scoped local verification passes, and the
record distinguishes simulated protocol tests from real optical tests. Once
hardware is connected, record USB HID/CDC enumeration, one-node click/release
and reconnect, then two-node roles and stuck-button recovery in the
[ESP-IDF qualification checklist](ESP-IDF-6.1-QUALIFICATION.md). Keep physical
results pending until measured and the optical purchasing line pending until a
supplier confirms a complete compatible kit and price.

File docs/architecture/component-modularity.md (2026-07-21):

<!-- SPDX-License-Identifier: MIT -->
# Component Modularity Architecture

PowerFinger is still greenfield. The repo should treat hardware substitutions
the way software treats interface-compatible implementations: a part is
swappable only when its electrical, mechanical, firmware, sourcing, safety, and
accessibility contracts are all still satisfied.

This document defines the first contract spine for the active
`R30-OLED-NONE-NONE` lane. It is intentionally small. It records current truth;
it does not claim that generators, schema validation, or manufacturing evidence
already exist.

## Current Contract Spine

| Layer | First contract file | Observed source of truth mirrored |
| --- | --- | --- |
| Variant composition | `variants/r30-oled-none-none.yaml` | Active packet manifest, firmware profile, BOM, CAD packet |
| Component anchors | `hardware/contracts/components.r30-oled-active.yaml` | Active BOM rows, substitution gates, first-board source caveats |
| Board interface | `hardware/contracts/board.r30-rigid-p0.yaml` | R30 KiCad interface contract and board-profile docs |
| Motion sensor | `hardware/contracts/sensor.paw3204.yaml` | PAW3204 driver, dual-footprint analysis, BOM notes |
| Battery envelope | `hardware/contracts/battery.lipo-protected-ring-100mah.yaml` | BOM, battery safety rules, CAD keepout, stackup template |
| Enclosure envelope | `hardware/contracts/enclosure.r30-serviceable-shell-v1.yaml` | R30 OpenSCAD model and stackup/coupon verification template |

These files are now locally checked contracts for the active lane. Packet docs
and schematics still remain authoritative for physical layout and measured
evidence, but the YAML records are no longer allowed to drift silently from the
variant ID, selected firmware drivers, board-profile Kconfig, BOM target, packet
manifest, or interface-contract non-claims.

## Boundary Rules

- A `variant` selects compatible contracts. It should not hide open risks.
- A `board` contract owns pins, buses, voltage assumptions, wake lines, service
  paths, antenna keep-outs, and firmware symbols.
- A `sensor` contract owns protocol, output shape, lens/aperture/focal
  geometry, and surface claims.
- A `battery` contract owns protected-cell requirements, connector/service
  requirements, charging assumptions, and safety evidence.
- An `enclosure` contract owns physical envelopes, service access, fit coupons,
  tolerance assumptions, and human-accessibility constraints.
- Firmware should eventually consume a generated board/profile fragment from
  the variant contract. For now, the contract cross-checks the existing
  `sdkconfig.defaults.r30_oled_none_none` path.

## What Is Still Prose-Only

- Some BOM alternates are still CSV notes and `SOURCE-ALTERNATIVES.md`, but the
  active BOM file, target, critical active-line anchors, U2 sensor substitution
  decision, charge controller alternates, charge-gate MOSFET alternates, and
  battery harness receptacle constraints are now checked in a dedicated
  component contract.
- CAD parameters are still OpenSCAD variables, not generated from envelope
  records. The checker compares headline envelope values only.
- Gesture intent is not yet a common API between physical input and HID output.
- EVT/DVT/PVT evidence is represented by checklists and gate docs, not a
  structured manufacturing evidence tree.
- Supplier qualification is documented as a baseline, not as tested alternates
  with pass/fail records.

## Local Drift Check

Run the local contract drift gate with:

```bash
scripts/check-contracts-local.sh
```

With no arguments, the gate runs the active-lane consistency check and the
fixture-backed negative self-test. The checker intentionally stays narrow. It
verifies that the active variant points at existing contracts, that every
contract has the minimum required schema shape, that referenced files exist,
that the active board/sensor/battery and enclosure contracts agree with each
other, that the R30 board contract agrees with the current board-profile
Kconfig pins, and that the packet manifest, BOM target, and interface contract
still name the active pin and non-claim seams. It also verifies the current
Shenzhen packet lane across the quote packet, first-contact template, Shenzhen
pairing doc, reference-manufacturer placeholder, and factory response-capture
sheet: `USB-HUB` stays the send-now quote path, `R30-OLED-NONE-NONE` stays
annex-only DFM/pre-fab review, and quote-vs-verified factory response capture
stays explicit. It also generates the expected
R30 board-profile `sdkconfig.defaults` fragment from the active variant plus
board contract and diffs that generated output against the checked-in firmware
fragment.
Production non-claims for `CHRG_STAT`, PAW3204 reset, PAW3204 motion wake, glass
support, and absent premium silicon are structured fields in the active
contracts rather than prose-only assertions.

The reusable checker lives in `scripts/contract_check.rb`. Its fixture-backed
self-test covers the current hard drift classes, and its print mode emits the
generated R30 board-profile fragment:

```bash
ruby scripts/contract_check.rb --self-test
ruby scripts/contract_check.rb --print-sdkconfig-profile
```

## Immediate Next Architecture Step

The checker implementation now has dedicated classes for cross-contract
validation, packet-text validation, generated sdkconfig validation, and
component/BOM validation, plus Shenzhen active-lane validation for the current
factory packet boundary. A shared validator base handles common checker
delegation, a schema/identity validator handles variant and contract shape, a
board-interface validator owns hard pin/interface expectations, and a dedicated
self-test fixture runner with named fixture objects, shared mutation helpers,
and a named fixture tree object for copied active-lane proof paths, plus a
focused sdkconfig profile generator. The generator owns sdkconfig value
derivation for selected firmware symbols, GPIO pin values, ADC channel values,
wake masks, and the disabled Hall rail. The board-interface validator owns the
active R30 pin expectation table and non-production behavior claims, so
`scripts/contract_check.rb` stays a CLI wrapper and shared contract helper
instead of owning board-profile semantics.

The next narrow implementation step is to move the self-test fixture catalog
behind a named fixture suite object so expected errors and mutations can be
extended without touching runner control flow. Keep `--print-sdkconfig-profile`
byte-for-byte stable, preserve hard-drift failure semantics, and leave KiCad
geometry parsing out of scope. Keep fixture coverage around:

- `variants/r30-oled-none-none.yaml`
- `hardware/contracts/board.r30-rigid-p0.yaml`
- `firmware/ring/sdkconfig.defaults.r30_oled_none_none`
- `hardware/ring/R30-OLED-NONE-NONE/kicad/INTERFACE-CONTRACT.md`

Validation should keep failing only on hard contract drift: pin mismatch,
missing contract reference, BOM/manifest mismatch, incompatible active
contracts, or a claimed firmware behavior with no firmware symbol. It should
not try to parse KiCad geometry yet.

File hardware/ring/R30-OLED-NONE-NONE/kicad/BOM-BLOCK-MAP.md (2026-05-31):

<!-- SPDX-License-Identifier: CERN-OHL-S-2.0 -->
# R30-OLED-NONE-NONE BOM To Block Map

This file keeps the first schematic capture aligned with the published BOM.
Read it together with [CAPTURE-BINDINGS.md](CAPTURE-BINDINGS.md) so the block
map and the actual symbol/footprint choices do not drift apart.

| Schematic block | BOM refs | What belongs in the first capture | Notes |
|---|---|---|---|
| MCU / radio | `U1`, `ANT1` | `ESP32-C3-MINI-1-N4` module and any required decoupling local to the module | The onboard module antenna is the default path; no external antenna should be required for P0 |
| Optical tracking | `U2`, `LED1`, `LENS1`, `R5` | PAW3204-class sensor, illumination path, lens-aligned notes, and SPI clock damping | ADNS-2080 remains the real backup path, but not the first P0 capture target |
| Primary click | `SW1` | Metal snap dome and any debounce/support passives | Keep the click path mechanically independent from battery service |
| Battery | `BT1` | Protected `80-100 mAh` LiPo connection and pack notes | Capture assumes integrated PCM remains mandatory |
| Charge path | `U3`, `R1`, `Q1` | TP4054, 20 kohm RPROG, and non-BOM fixture-fed VBUS service jumper | Keep this close to USB/VBUS entry. This P0 does not claim MCU charge-enable control; fixture VBUS presence controls charge service |
| Regulation | `U4`, `C2` plus DNP placeholders `C1`/`C3` | RT9080 power tree and board-level decoupling | `C1`/`C3` are retained as schematic-only DNP placeholders until the next schematic-driven PCB update; do not substitute a high-Iq LDO in the P0 capture |
| Thermal safety | `NTC1`, `R3` | NTC divider and sensing path | Place to reflect cell temperature, not convenient routing |
| Battery / USB sense | `R7`, `R8`, `R9`, `R10` | BDFL-accepted first-board VBAT and VBUS resistor dividers to the MCU resources in the interface contract | `R7`/`R8` = `100k`/`100k`; `R9`/`R10` = `220k`/`100k`. Reintroducing onboard charge-enable switching remains an explicit substitution |
| Charge status | `TP_CHRG` | TP4054 `CHRG_STAT` fixture status pad with no onboard pull-up | This is fixture-testable status, not a firmware-consumed claim yet; the fixture must provide a pull-up if status is measured |
| USB / service entry | `J1`, `R2`, `D1` | Off-board same-net USB service pads, CC pull-downs, and rail-less USB data ESD protection | The service/debug USB path is a first-pass P0 assumption, not a hidden dev-only hack; keep D1 as a D+/D- shunt rather than a VBUS-clamped protection island |
| Shell / glide interface | `SHELL1`, `RIM1`, `PAD1` | Mechanical notes and keep-out references, not electrical symbols | These should still be called out in the project notes so layout respects them |

## Capture Boundary

The first schematic should capture everything needed for the Standard optical
ring claim and nothing that belongs exclusively to later Pro or hedge variants.

The first PCB pass used to expose `VBAT_SENSE`, `VBUS_DETECT`, and
`CHRG_STAT` as pads only. The active BOM CSV and KiCad files now carry
`R7`/`R8` (VBAT_SENSE 100k/100k divider), `R9`/`R10` (VBUS_DETECT 220k/100k
divider), and `TP_CHRG` as a fixture-observed CHRG_STAT pad without an onboard
pull-up. Treat those as the BDFL-accepted first rigid P0 packet decision, not
hidden extras. The remaining truth is narrower: the board is now ERC/DRC/parity
clean, board-house output constraints and physical fit/stackup evidence are
still open, onboard charge-enable switching needs an explicit packet update,
and `CHRG_STAT` is only a fixture status/test pad for this board pass.
Production status behavior needs an explicit MCU allocation, Kconfig symbol,
firmware consumer, and focused tests. See
[CURRENT-VIOLATIONS.md](CURRENT-VIOLATIONS.md) for the ERC/DRC snapshot that
gates this packet.

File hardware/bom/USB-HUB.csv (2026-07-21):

Ref | Qty | Description | Value | Package | Manufacturer | MPN | Supplier | Supplier PN | Unit Cost (1-10) | Notes
U1 | 1 | BLE + USB OTG SoC module | ESP32-S3-MINI-1-N8 | SMD module | Espressif | ESP32-S3-MINI-1-N8 | LCSC | C2913206 | $3.00–4.00 | 8MB flash. Native USB OTG. Alt: ESP32-S3-MINI-1-N4R2 (C3013941, 4MB flash + 2MB PSRAM). Keep native USB in the main data path.
J1 | 1 | USB-A male connector | USB-A plug | Through Hole | SOFNG | USB-05 | LCSC | C112454 | $0.04–0.08 | Locked P0 dongle connector. Use the SOFNG USB-05 datasheet geometry for the first footprint. LCSC category text may call this style a receptacle, but the manufacturer drawing is USB-A/M and that male-plug geometry is the load-bearing design intent here.
U2 | 1 | 3.3V low-Iq LDO regulator | RT9080-33GJ5 | SOT-23-5 | Richtek | RT9080-33GJ5 | LCSC | C882092 | $0.15 | Active-lane regulator baseline so the hub does not silently depend on dev-board power assumptions. Keep the first custom hub aligned with the same regulator family already published for the rings.
C1 | 2 | Decoupling capacitor | 100nF | 0402 | — | — | LCSC | — | $0.01 | Standard ceramic MLCC. One local to the regulator/power entry, one local to the ESP32-S3 module.
C2 | 1 | Bulk capacitor | 10µF | 0603 | — | — | LCSC | — | $0.01 | VBUS-side bulk/input capacitor for the hub power entry. Locking 0603 avoids pretending a marginal 0402 part will hold its capacitance honestly at bias.
C3 | 1 | LDO output capacitor | 1µF effective | 0603 | — | — | LCSC | — | $0.01 | Required for the RT9080-33GJ5 regulation path. Locking 0603 gives more realistic effective capacitance margin for the first board.
C4 | 1 | EN RC support capacitor | 1µF | 0402 | — | — | LCSC | — | $0.01 | First-board EN support capacitor so the ESP32-S3 EN path is not left floating. Commodity MLCC; keep sourceable but do not over-spec before bring-up.
R1 | 2 | USB data line resistors | — | 0402 | — | — | LCSC | — | $0.01 | Per USB spec. Value depends on USB mode.
D1 | 1 | USB ESD protection array | USBLC6-2SC6 | SOT-23-6 | STMicroelectronics | USBLC6-2SC6 | LCSC | C7519 | $0.07–0.11 | Locked P0 USB data/VBUS protector. Official USB 2.0-capable two-line array with VBUS protection. Place at the connector entry, not after a long stub.
LED1 | 1 | Status LED (connection indicator) | green | 0402 | — | — | LCSC | — | $0.01 | Optional. Shows pairing/connection state.
R2 | 1 | LED current limit resistor | 1kΩ | 0402 | — | — | LCSC | — | $0.01 | For status LED.
R3 | 1 | EN pull resistor | 10kΩ | 0402 | — | — | LCSC | — | $0.01 | First-board EN support resistor paired with C4. Commodity resistor; exact source can follow the assembly house's standard 0402 stock.
SW1 | 1 | Boot/reset service button | tactile switch | service-size TBD | — | — | LCSC | — | $0.03 | Bring-up and recovery access. Do not force a 6x6mm tact into the stepped direct-plug body if that breaks the board envelope; a smaller tact or pad-actuated recovery path is acceptable. If a single switch is kept, the board still needs service pads for the rest of the bootstrap path.
PCB1 | 1 | Rigid PCB | — | stepped USB-A nose + 54 x 26 mm body | JLCPCB | — | — | — | $0.30–0.50 | 2-layer stepped direct-plug board. Host-side USB-A nose widens to the 54 x 26 mm module/service body; host fit and adjacent-port clearance remain unmeasured.
ENCL1 | 1 | Enclosure | — | stepped direct-plug shell | — | — | — | — | $0.30–0.50 | 3D-printed prototype enclosure should mechanically support the connector, follow the stepped USB-A nose plus 54 x 26 mm body, and reopen for service. Heat-shrink alone is not the preferred P0 service baseline; host-fit and adjacent-port clearance remain unmeasured.
 |  |  |  |  |  |  |  |  |  | —
 |  | TOTAL (estimated) |  |  |  |  |  |  | ~$4.23–6.28 | Dominated by ESP32-S3 module cost; includes first-pass USB protection, explicit 3.3V regulation, and the EN support pair.
 |  | TARGET BOM |  |  |  |  |  |  | ~$5–6

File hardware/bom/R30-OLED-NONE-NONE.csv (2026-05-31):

Ref | Qty | Description | Value | Package | Manufacturer | MPN | Supplier | Supplier PN | Unit Cost (1-10) | Notes
U1 | 1 | BLE SoC module (WiFi + BLE 5.0) | ESP32-C3-MINI-1-N4 | SMD module | Espressif | ESP32-C3-MINI-1-N4 | LCSC | C2838502 | $2.01 | NRND — successor is ESP32-C3-MINI-1-N4X (chip rev v1.1, same pinout). Alt: ESP32-C3-MINI-1-H4 (C2934569). Any ESP32-C3 module with 4MB flash.
U2 | 1 | Optical mouse sensor (LED illumination) | PAW3204DB-TJ3L | 8-pin optical | PixArt | PAW3204DB-TJ3L | AliExpress | — | $0.50–1.50 | Active P0 choice: PAW3204DB-TJ3L sensor+lens/emitter kit. Verified fallback class: ADNS-2080, but only after footprint, lens, aperture, and firmware-profile evaluation. YS8205 is NOT a standalone sensor (integrated USB mouse controller — not viable). Do not substitute generic USB mouse ICs or unverified SPI sensors into this first-board packet.
LED1 | 0 | Optional discrete illumination LED (fallback only) | — | 0603 or axial | — | — | — | — | — | Dropped from first capture per CAPTURE-BINDINGS.md — PAW3204 is sourced as a sensor+lens+emitter kit so U2/LENS1 already provide the illumination path. Reinstate as a discrete part only if a bare-sensor supply path becomes the only option.
LENS1 | 1 | Sensor lens + clip | — | sensor-specific | PixArt | — | AliExpress | — | $0.10–0.30 | Usually sold as sensor + lens kit. Must match sensor package.
SW1 | 1 | Metal snap dome switch | 5mm 200gf | 5mm round | Snaptron | SQ-05400N | DigiKey | — | $0.05–0.15 | Alt: any 4–6mm metal dome, 150–250gf actuation. Murata, C&K also supply.
BT1 | 1 | LiPo battery (service-harness terminated) | 80–100mAh 3.7V | pouch cell with integrated PCM and replaceable service harness | — | — | AliExpress | — | $0.80–1.50 | Cell ships with a replaceable harness/fixture tail that lands on J_BAT service pads rather than an onboard JST-SH body. Size constraint: must fit in ring shell. Target ≤20x15x4mm. Must include integrated PCM and UN 38.3 documentation. No harvested cells. Harness must preserve reopenable-seam replaceability without de-soldering the cell.
J_BAT | 1 | Off-board battery service pads | VBAT+/VBAT-/MP shield pads | PCB pads | PowerFinger | OFFBOARD-BAT-SERVICE-PADS | — | — | $0.00 | Source-controlled same-net battery service pad interface. Replaces the onboard JST-SH receptacle body; first hardware still needs a replaceable harness or fixture so the cell is not direct-soldered.
U3 | 1 | LiPo charge controller | TP4054 | SOT-23-5 | — | TP4054 | LCSC | C32574 | $0.05 | Alt: LTC4054ES5-4.2 (Analog Devices, DigiKey 960438 — true pin-compatible). TP4056 requires SOP-8 footprint (NOT drop-in). MCP73831 SOT-23-5 has different pinout (verify PCB layout). No NTC input — see NTC/MOSFET lines below.
U4 | 1 | 3.3V ultra-low-Iq LDO regulator | RT9080-33GJ5 | SOT-23-5 | Richtek | RT9080-33GJ5 | LCSC | C882092 | $0.15 | 0.5µA quiescent — critical for deep sleep (AP2112K's 55µA dominates sleep budget 11:1). Alt: XC6220B331MR (8µA Iq). NOT AP2112K.
J1 | 1 | Off-board USB service pads | USB2/VBUS/CC/GND/SH service pads | PCB pads | PowerFinger | OFFBOARD-SERVICE-PADS | — | — | $0.00 | Source-controlled same-net USB charge/program service pad interface. Requires an external fixture or pogo harness; no onboard USB-C receptacle body is claimed in this packet.
C1A | 1 | MCU VREG_3V3 decoupling capacitor | 100nF | 0402 | — | — | LCSC | — | $0.01 | Local ESP32-C3 3V3/GND1 decoupler placed as C1A on the routed first board.
C2 | 1 | Bulk capacitor (LDO input) | 10µF | 0402 or 0603 | — | — | LCSC | — | $0.01 | Input cap for LDO at U4 VIN.
C1B | 1 | PAW3204 sensor VREG_3V3 decoupling capacitor | 100nF | 0402 | — | — | LCSC | — | $0.01 | Local PAW3204 VDD/VDDA decoupler placed as C1B on the routed first board.
R1 | 1 | Charge current set resistor | 20kΩ (for ~50mA) | 0402 | — | — | LCSC | — | $0.01 | IBAT = 1000V/RPROG. 20kΩ → 50mA (0.625C on 80mAh). 10kΩ (100mA) produces unsafe temps in sealed ring — see BATTERY-SAFETY.md §5.
R2A | 1 | USB service CC1 pull-down resistor (Rd) | 5.1kΩ | 0402 | — | — | LCSC | — | $0.01 | Required if the service fixture presents a USB-C source path. Rd on CC1 so the board presents as a sink/device. Pair with R2B (CC2).
R2B | 1 | USB service CC2 pull-down resistor (Rd) | 5.1kΩ | 0402 | — | — | LCSC | — | $0.01 | Sibling of R2A on CC2. Both Rd's are preserved for fixture-based USB-C sink behavior.
NTC1 | 1 | NTC thermistor (cell temp monitoring) | 10kΩ at 25°C, B3950 | 0402 | — | — | LCSC | — | $0.02 | Bonded to cell or adjacent on PCB. Required — TP4054 has no temp monitoring. See BATTERY-SAFETY.md §7.1.
R3 | 1 | NTC voltage divider resistor | 10kΩ | 0402 | — | — | LCSC | — | $0.01 | ADC scaling for NTC thermistor.
Q1 | 0 | PCB copper VBUS service jumper | VBUS_SERVICE_JUMPER | SOT-23 service land | PowerFinger | PCB-COPPER-JUMPER | — | — | $0.00 | Non-BOM copper jumper on the former Q1 land. Fixture-fed VBUS now reaches TP4054 VCC directly; no onboard MCU-controlled charge-enable switch; no Q2 driver, R4 pull-up, or R6 pulldown is populated in this P0 packet.
TP_CHRG | 0 | Fixture-observed charger-status test pad | CHRG_STAT open-drain service pad | PCB pad | PowerFinger | TESTPAD-CHRG-STATUS | — | — | $0.00 | Non-BOM fixture status pad. No onboard pull-up; external fixture must provide pull-up if CHRG_STAT is measured.
TP_MOT | 0 | PAW3204 motion bring-up test pad | SENSOR_MOTION_N local pad | PCB pad | PowerFinger | TESTPAD-SENSOR-MOTION | — | — | $0.00 | Non-BOM local bring-up pad only; no MCU wake claim in this P0.
TP_RST | 0 | PAW3204 reset bring-up test pad | SENSOR_NRESET local pad | PCB pad | PowerFinger | TESTPAD-SENSOR-RESET | — | — | $0.00 | Non-BOM local bring-up pad only; no MCU reset-control claim in this P0.
TP_VBAT | 0 | VBAT_SENSE divider service test pad | VBAT_SENSE local pad | PCB pad | PowerFinger | TESTPAD-VBAT-SENSE | — | — | $0.00 | Non-BOM ADC bring-up pad after R7/R8 divider.
TP_VBUS | 0 | VBUS_DETECT divider service test pad | VBUS_DETECT local pad | PCB pad | PowerFinger | TESTPAD-VBUS-DETECT | — | — | $0.00 | Non-BOM GPIO bring-up pad after R9/R10 divider.
R7 | 1 | VBAT_SENSE divider top | 100kΩ | 0402 | — | — | LCSC | — | $0.01 | Packet recommendation for first rigid P0. With R8=100kΩ, divides VBAT_PROTECTED (max 4.2V) by 2 → max 2.1V at ESP32-C3 GPIO0 / ADC1_CH0. Always-on divider draw is ≈21µA at 4.2V; accepted for first-board ADC reliability and safety bring-up, with a switched or higher-value divider left as a future sleep-floor optimization.
R8 | 1 | VBAT_SENSE divider bottom | 100kΩ | 0402 | — | — | LCSC | — | $0.01 | Packet recommendation for first rigid P0. Pair with R7; 0402 commodity resistor keeps the divider repairable and multi-source.
R9 | 1 | VBUS_DETECT divider top | 220kΩ | 0402 | — | — | LCSC | — | $0.01 | Packet recommendation for first rigid P0. With R10=100kΩ, divides VBUS_5V down to ~1.56V at GPIO3 — clearly digital-high when USB is present, near 0V when absent. Draw is ≈16µA only from USB VBUS while plugged in, not from the cell.
R10 | 1 | VBUS_DETECT divider bottom | 100kΩ | 0402 | — | — | LCSC | — | $0.01 | Packet recommendation for first rigid P0. Pair with R9; leaves VBUS_DETECT simple, offline, and testable without an IC dependency.
D1 | 1 | USB ESD protection array | TPD2E2U06DCK-class rail-less dual TVS | SC-70/SOT-323 | Texas Instruments | TPD2E2U06DCK | LCSC | — | $0.03–0.10 | Protect D+ and D- at the connector without a VBUS clamp branch. Rail-less data-line ESD is the P0 routing lock for the constrained ring board; equivalent dual-channel low-capacitance SC-70/SOT-323 parts are acceptable only if the pad order preserves the committed shunt layout.
R5 | 1 | SPI clock series damping resistor | 33–100Ω | 0402 | — | — | LCSC | — | $0.01 | Place at the MCU side of the PAW3204 clock path. Cheap emissions-risk reduction per REGULATORY-PRESCAN.md.
PCB1 | 1 | Rigid PCB (P0) with flex-migration zone discipline | — | custom | JLCPCB/PCBWay | — | — | — | $0.50–2.00 | P0 is rigid per CAPTURE-BINDINGS.md — flex/rigid-flex respin is preserved by the zone-boundary rule in PLACEMENT-CONSTRAINTS.md, not by fabricating flex for the first board. Prototype qty rigid pricing.
SHELL1 | 1 | 3D-printed ring shell (30° angle) | — | parametric | — | — | — | — | $0.50–1.00 | Nylon (SLS/MJF) or PLA/PETG (FDM). Parametric for finger_circumference.
RIM1 | 1 | Structural rim (integral to shell) | POM or nylon | — | — | — | — | — | $0.00 | Part of shell print. See GLIDE-SYSTEM.md.
PAD1 | 4 | UHMWPE glide pads | 0.5mm thick | punched disc | — | — | McMaster-Carr | — | $0.02–0.05 | Punched from UHMWPE sheet stock. See GLIDE-SYSTEM.md for material rationale.
ANT1 | 1 | BLE PCB antenna or ceramic chip antenna | 2.4GHz | — | — | — | LCSC | — | $0.10–0.30 | ESP32-C3-MINI-1 has onboard antenna. External only if module uses U.FL variant.
 |  |  |  |  |  |  |  |  |  | —
 |  | TOTAL (estimated) |  |  |  |  |  |  | ~$4.97–8.77 | Lower end = volume pricing. Upper end = prototype qty with off-board USB and battery service pads, USB protection passives, and packet-recommended sense parts (R7-R10). LED1, the onboard CHRG_STAT pull-up, and the active charge-gate parts dropped; PCB1 rigid-only. Charging service is controlled by fixture VBUS presence on this P0 rather than an onboard MCU charge-enable switch.
 |  | TARGET BOM |  |  |  |  |  |  | ~$9 | At small prototype quantities.

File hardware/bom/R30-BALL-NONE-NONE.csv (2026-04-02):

Ref | Qty | Description | Value | Package | Manufacturer | MPN | Supplier | Supplier PN | Unit Cost (1-10) | Notes
U1 | 1 | BLE SoC module (WiFi + BLE 5.0) | ESP32-C3-MINI-1-N4 | SMD module | Espressif | ESP32-C3-MINI-1-N4 | LCSC | C2838502 | $2.01 | NRND — successor is ESP32-C3-MINI-1-N4X (chip rev v1.1, same pinout). All ring variants share this module.
U2 | 4 | Hall effect sensor (linear) | DRV5053 or equivalent | SOT-23 | Texas Instruments | DRV5053VAQDBZR | LCSC | — | $0.15–0.30 | ~3mA typ per sensor (12mA total) vs SS49E at 6mA per (24mA total). Must power-gate via MOSFET in sleep — no built-in sleep mode. AH3503 is NOT pin-compatible (different pin ordering, default TO-92 package). Alt: SS49E (higher current).
BALL1 | 1 | Steel ball | 5mm diameter | — | — | — | AliExpress/McMaster | — | $0.05–0.10 | Chrome steel or stainless. Must be ferromagnetic or paired with magnetized rollers.
ROLLER1 | 4 | Roller spindle with magnet | ~2mm diameter | custom or modified | — | — | — | — | $0.20–0.50 | Roller + small magnet (1x1mm N52 neodymium). May need to be custom-assembled from magnet + metal rod.
MAG1 | 4 | Neodymium magnet for roller | 1x1mm disc N52 | — | — | — | AliExpress | — | $0.05–0.10 | Epoxied to roller spindle. Alt: magnetized roller (single piece).
SW1 | 1 | Metal snap dome switch | 5mm 200gf | 5mm round | Snaptron | SQ-05400N | DigiKey | — | $0.05–0.15 | Same as optical ring.
BT1 | 1 | LiPo battery | 80–100mAh 3.7V | pouch cell with integrated PCM | — | — | AliExpress | — | $0.80–1.50 | Same constraints as optical ring: integrated PCM, UN 38.3 documentation, no harvested cells.
U3 | 1 | LiPo charge controller | TP4054 | SOT-23-5 | — | TP4054 | LCSC | C32574 | $0.05 | Alt: LTC4054ES5-4.2 (Analog Devices, DigiKey 960438 — true pin-compatible). No NTC input — see NTC/MOSFET lines below.
U4 | 1 | 3.3V ultra-low-Iq LDO regulator | RT9080-33GJ5 | SOT-23-5 | Richtek | RT9080-33GJ5 | LCSC | C882092 | $0.15 | 0.5µA Iq. See optical ring BOM for rationale.
J1 | 1 | USB-C connector (charging only) | USB-C 2.0 receptacle | SMD | — | — | LCSC | — | $0.10–0.30 | Same as optical ring.
C1 | 2 | Decoupling capacitor | 100nF | 0402 | — | — | LCSC | — | $0.01 | Standard ceramic MLCC.
C2 | 1 | Bulk capacitor | 10µF | 0402 or 0603 | — | — | LCSC | — | $0.01 | Input cap for LDO.
R1 | 1 | Charge current set resistor | 20kΩ (for ~50mA) | 0402 | — | — | LCSC | — | $0.01 | 20kΩ → 50mA (0.625C on 80mAh). 10kΩ (100mA) produces unsafe temps in sealed ring — see BATTERY-SAFETY.md §5.
NTC1 | 1 | NTC thermistor (cell temp monitoring) | 10kΩ at 25°C, B3950 | 0402 | — | — | LCSC | — | $0.02 | Bonded to cell or adjacent on PCB. Required — TP4054 has no temp monitoring. See BATTERY-SAFETY.md §7.1.
R3 | 1 | NTC voltage divider resistor | 10kΩ | 0402 | — | — | LCSC | — | $0.01 | ADC scaling for NTC thermistor.
Q1 | 1 | P-ch MOSFET (charge enable/disable) | SI2301 or equiv | SOT-23 | — | SI2301CDS | LCSC | — | $0.03 | On VBUS before TP4054 VCC. GPIO-controlled. Gate floats high (off) = charge disabled (safe default). See BATTERY-SAFETY.md §7.1.
R4 | 1 | MOSFET gate pull-up resistor | 100kΩ | 0402 | — | — | LCSC | — | $0.01 | Default-off gate bias for Q1.
PCB1 | 1 | Flex or rigid-flex PCB | — | custom | JLCPCB/PCBWay | — | — | — | $2.00–5.00 | Needs 4 analog inputs for Hall sensors. Same prototype pricing as optical.
SHELL1 | 1 | 3D-printed ring shell (30° angle) | — | parametric | — | — | — | — | $0.50–1.00 | Must include ball socket + roller mounts. More complex geometry than optical shell.
SOCKET1 | 1 | Ball socket assembly | — | custom 3D print | — | — | — | — | $0.00 | Integrated into shell. Holds ball with ≤0.5mm clearance.
 |  |  |  |  |  |  |  |  |  | —
 |  | TOTAL (estimated) |  |  |  |  |  |  | ~$7.00–13.00 | Roller/magnet assembly is the cost uncertainty.
 |  | TARGET BOM |  |  |  |  |  |  | ~$11 | At small prototype quantities.

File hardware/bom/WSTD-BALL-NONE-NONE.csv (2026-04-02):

Ref | Qty | Description | Value | Package | Manufacturer | MPN | Supplier | Supplier PN | Unit Cost (1-10) | Notes
U1 | 1 | BLE SoC module (WiFi + BLE 5.0) | ESP32-C3-MINI-1-N4 | SMD module | Espressif | ESP32-C3-MINI-1-N4 | LCSC | C2838502 | $2.01 | NRND — successor is ESP32-C3-MINI-1-N4X (chip rev v1.1, same pinout). Same module as all ring variants.
U2 | 4 | Hall effect sensor (linear) | DRV5053 or equivalent | SOT-23 | Texas Instruments | DRV5053VAQDBZR | LCSC | — | $0.15–0.30 | ~3mA typ per sensor vs SS49E at 6mA. Must power-gate in sleep. AH3503 is NOT pin-compatible (different pin ordering, default TO-92). Alt: SS49E (higher current).
BALL1 | 1 | Steel ball | 5mm diameter | — | — | — | AliExpress/McMaster | — | $0.05–0.10 | Same as ball ring.
ROLLER1 | 4 | Roller spindle with magnet | ~2mm diameter | custom | — | — | — | — | $0.20–0.50 | Same as ball ring.
MAG1 | 4 | Neodymium magnet for roller | 1x1mm disc N52 | — | — | — | AliExpress | — | $0.05–0.10 | Same as ball ring.
SW1 | 1 | Kailh micro switch (barrel button) | Kailh GM8.0 | 12.8x5.8x6.5mm | Kailh | GM8.0 | AliExpress/Kailh direct | — | $0.20–0.50 | Thumb-operated barrel button. 80M cycle life. Alt: Omron D2FC-F-7N (multi-source fallback).
SW2 | 1 | Metal snap dome (tip press-down) | 5mm 200gf | 5mm round | Snaptron | SQ-05400N | DigiKey | — | $0.05–0.15 | Optional: under ball for press-down click (Pattern E). May omit for prototype.
BT1 | 1 | LiPo battery | 100–150mAh 3.7V | pouch cell with integrated PCM | — | — | AliExpress | — | $1.00–2.00 | Wand body has more room. Target ≤40x10x5mm. Must include integrated PCM and UN 38.3 documentation.
U3 | 1 | LiPo charge controller | TP4054 | SOT-23-5 | — | TP4054 | LCSC | C32574 | $0.05 | Alt: LTC4054ES5-4.2 (Analog Devices, DigiKey 960438 — true pin-compatible). No NTC input — see NTC/MOSFET lines below.
U4 | 1 | 3.3V ultra-low-Iq LDO regulator | RT9080-33GJ5 | SOT-23-5 | Richtek | RT9080-33GJ5 | LCSC | C882092 | $0.15 | 0.5µA Iq. See optical ring BOM for rationale.
J1 | 1 | USB-C connector (charging) | USB-C 2.0 receptacle | SMD | — | — | LCSC | — | $0.10–0.30 | At wand body end, opposite tip.
C1 | 2 | Decoupling capacitor | 100nF | 0402 | — | — | LCSC | — | $0.01
C2 | 1 | Bulk capacitor | 10µF | 0402 or 0603 | — | — | LCSC | — | $0.01
R1 | 1 | Charge current set resistor | 20kΩ (for ~50mA) | 0402 | — | — | LCSC | — | $0.01 | 20kΩ → 50mA (0.5C on 100mAh). 10kΩ (100mA) produces unsafe temps in sealed enclosure — see BATTERY-SAFETY.md §5.
NTC1 | 1 | NTC thermistor (cell temp monitoring) | 10kΩ at 25°C, B3950 | 0402 | — | — | LCSC | — | $0.02 | Bonded to cell or adjacent on PCB. Required — TP4054 has no temp monitoring. See BATTERY-SAFETY.md §7.1.
R3 | 1 | NTC voltage divider resistor | 10kΩ | 0402 | — | — | LCSC | — | $0.01 | ADC scaling for NTC thermistor.
Q1 | 1 | P-ch MOSFET (charge enable/disable) | SI2301 or equiv | SOT-23 | — | SI2301CDS | LCSC | — | $0.03 | On VBUS before TP4054 VCC. GPIO-controlled. Gate floats high (off) = charge disabled (safe default). See BATTERY-SAFETY.md §7.1.
R4 | 1 | MOSFET gate pull-up resistor | 100kΩ | 0402 | — | — | LCSC | — | $0.01 | Default-off gate bias for Q1.
PCB1 | 1 | Rigid PCB | — | ~8mm wide strip | JLCPCB | — | — | — | $0.50–1.00 | Rigid PCB fits in tube body. Simpler than ring flex PCB.
TUBE1 | 1 | Wand body tube | 8mm OD × 120mm | aluminum or stainless | — | — | McMaster/AliExpress | — | $1.00–2.00 | Cut to length. Alt: 3D-printed for prototype.
TIP1 | 1 | Tip assembly (ball socket) | — | custom 3D print | — | — | — | — | $0.50 | Holds ball + rollers + Hall sensors at pen tip. Press-fits into tube.
CAP1 | 1 | End cap (USB-C end) | — | custom 3D print | — | — | — | — | $0.20 | Holds USB-C connector + battery. Press-fits into tube.
 |  |  |  |  |  |  |  |  |  | —
 |  | TOTAL (estimated) |  |  |  |  |  |  | ~$8.00–14.00
 |  | TARGET BOM |  |  |  |  |  |  | ~$14 | At small prototype quantities.

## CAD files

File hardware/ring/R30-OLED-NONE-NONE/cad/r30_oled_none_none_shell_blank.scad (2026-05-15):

// SPDX-License-Identifier: CERN-OHL-S-2.0
//
// Serviceable first-board shell packet for the active optical ring lane.
// This is an honest mechanical packet, not a validated enclosure.

$fn = 96;

finger_circumference_mm = 60;
sensor_angle_deg = 30;
band_width_mm = 18;
shell_height_mm = 8.0;
wall_thickness_mm = 1.6;
radial_thickness_mm = 7.0;
rim_height_mm = 2.8;
rim_radial_width_mm = 2.6;
glide_pad_thickness_mm = 0.5;
sensor_aperture_diameter_mm = 6.2;
sensor_platform_offset_mm = 8.5;
service_seam_height_mm = 5.2;
lid_top_skin_mm = 1.2;
lid_skirt_height_mm = 1.4;
seam_clearance_mm = 0.25;
service_pry_slot_mm = [4.8, 2.0, 1.4];

// First routed PCB facts, mapped from kicad/r30_oled_none_none.kicad_pcb.
// Board center is KiCad (120.500, 100.000); +X points toward the ESP32 antenna.
pcb_size_mm = [43.0, 18.0, 1.0];
pcb_clearance_mm = 0.35;
pcb_center_z_mm = 3.6;
pcb_top_z_mm = pcb_center_z_mm + pcb_size_mm[2] / 2;
pcb_tray_clearance_mm = [pcb_size_mm[0] + (2 * pcb_clearance_mm),
                         pcb_size_mm[1] + (2 * pcb_clearance_mm),
                         pcb_size_mm[2] + 0.6];
pcb_tray_center_mm = [0, 0, pcb_center_z_mm];

pcb_pod_margin_mm = [1.8, 1.5, 0];
pcb_pod_size_mm = [pcb_size_mm[0] + (2 * pcb_pod_margin_mm[0]),
                   pcb_size_mm[1] + (2 * pcb_pod_margin_mm[1]),
                   shell_height_mm];
pcb_pod_corner_radius_mm = 2.2;

service_access_center_mm = [-17.85, 0.0, pcb_top_z_mm + 0.70];
service_access_opening_mm = [2.6, 8.2, 1.8];
service_fixture_keepout_mm = [4.2, 7.4, 1.8];

sensor_pcb_center_mm = [-4.00, 0.0, 1.7];
dome_switch_center_mm = [-6.15, -4.22, pcb_top_z_mm + 0.45];
battery_connector_center_mm = [-11.90, -5.75, pcb_top_z_mm + 0.35];
antenna_keepout_center_mm = [17.575, 0.0, pcb_top_z_mm + 1.2];
antenna_keepout_mm = [7.85, 16.7, 2.4];

board_rail_length_mm = 34.0;
board_rail_size_mm = [board_rail_length_mm, 0.9, 0.75];
board_rail_center_z_mm = pcb_center_z_mm - pcb_size_mm[2] / 2 - 0.30;
board_end_stop_size_mm = [0.9, 1.0, 1.2];

lid_compression_pad_size_mm = [5.0, 1.2, 0.7];
lid_compression_pad_centers_mm = [
    [-13.5, 8.0, service_seam_height_mm - 0.35],
    [4.8, 8.0, service_seam_height_mm - 0.35]
];

dome_pocket_diameter_mm = 6.6;
dome_actuator_relief_diameter_mm = 3.2;
dome_pocket_depth_mm = 1.5;

battery_harness_channel_mm = [13.0, 3.2, 2.0];
battery_harness_channel_center_mm = [-6.7, -3.9, pcb_top_z_mm + 0.45];
battery_lift_window_mm = [22.0, 16.5, shell_height_mm - service_seam_height_mm - lid_top_skin_mm + 0.1];
battery_lift_window_center_mm = [-4.6, 0.8, service_seam_height_mm + 0.85];
battery_service_loop_relief_mm = [12.0, 6.0, 1.6];
battery_service_loop_center_mm = [-1.3, 4.6, pcb_top_z_mm + 0.20];

service_screw_centers_mm = [[-15.0, 6.9], [6.8, 6.9]];

// Battery envelope remains a fit proxy until a real protected cell is chosen.
battery_keepout_mm = [20, 15, 4.2];
sensor_cavity_mm = [11.5, 8.0, 2.6];
module_keepout_mm = [14, 12, 3.2];

battery_center_mm = [-4.1, 0.8, 4.7];
sensor_cavity_center_mm = [sensor_pcb_center_mm[0], sensor_pcb_center_mm[1], 2.6];
module_center_mm = [5.3, 0.0, 3.2];

screw_boss_outer_diameter_mm = 3.8;
screw_pilot_diameter_mm = 1.25;
screw_clearance_diameter_mm = 1.65;
screw_head_diameter_mm = 3.2;
screw_head_depth_mm = 1.2;

explode_gap_mm = 5.0;
show_exploded_view = true;
show_reference_solids = true;
show_reference_fasteners = true;

// Export modes:
//   shell
//   service_access_coupon
//   board_retention_coupon
//   lid_pad_coupon
//   battery_harness_coupon
//   service_lid_coupon
//   fit_coupons
export_mode = "shell";

coupon_base_thickness_mm = 1.2;
coupon_wall_mm = 1.8;
coupon_bridge_thickness_mm = 1.2;
coupon_board_slide_clearance_mm = 0.20;
service_lid_coupon_tongue_mm = [22.4, 12.4, lid_skirt_height_mm];

inner_diameter_mm = finger_circumference_mm / PI;
outer_diameter_mm = inner_diameter_mm + (2 * radial_thickness_mm);
inner_radius_mm = inner_diameter_mm / 2;
outer_radius_mm = outer_diameter_mm / 2;

seam_socket_outer_diameter_mm = outer_diameter_mm - 1.2;
seam_socket_inner_diameter_mm = seam_socket_outer_diameter_mm - 2.2;
male_skirt_outer_diameter_mm = seam_socket_outer_diameter_mm - seam_clearance_mm;
male_skirt_inner_diameter_mm = seam_socket_inner_diameter_mm + seam_clearance_mm;
lid_z_offset_mm = show_exploded_view ? explode_gap_mm : 0;

assert(sensor_angle_deg > 0 && sensor_angle_deg < 60);
assert(outer_diameter_mm > inner_diameter_mm + 2);
assert(shell_height_mm > service_seam_height_mm + 1.0);
assert(service_seam_height_mm > 3.8);
assert(lid_top_skin_mm > 0.8);
assert(band_width_mm >= sensor_aperture_diameter_mm + 6);
assert(seam_socket_inner_diameter_mm > inner_diameter_mm + 2.0);
assert(pcb_pod_size_mm[1] >= pcb_size_mm[1] + 2.0);
assert(service_access_opening_mm[1] > 7.5);
assert(service_screw_centers_mm[1][0] < antenna_keepout_center_mm[0] - antenna_keepout_mm[0] / 2);
assert(export_mode == "shell" ||
       export_mode == "service_access_coupon" ||
       export_mode == "board_retention_coupon" ||
       export_mode == "lid_pad_coupon" ||
       export_mode == "battery_harness_coupon" ||
       export_mode == "service_lid_coupon" ||
       export_mode == "fit_coupons",
       str("unknown export_mode: ", export_mode));

module clipped_to_lower_segment() {
    intersection() {
        children();
        translate([-outer_diameter_mm,
                   -outer_diameter_mm,
                   -rim_height_mm - 0.2])
            cube([2 * outer_diameter_mm,
                  2 * outer_diameter_mm,
                  service_seam_height_mm + rim_height_mm + 0.2]);
    }
}

module clipped_to_upper_segment() {
    intersection() {
        children();
        translate([-outer_diameter_mm,
                   -outer_diameter_mm,
                   service_seam_height_mm])
            cube([2 * outer_diameter_mm,
                  2 * outer_diameter_mm,
                  shell_height_mm - service_seam_height_mm + 0.2]);
    }
}

module outer_shell_envelope() {
    union() {
        ring_body();
        board_pod_envelope();
        lower_rim();
    }
}

module ring_body() {
    cylinder(h = shell_height_mm, d = outer_diameter_mm);
}

module rounded_box(size, radius) {
    hull() {
        for (x = [-size[0] / 2 + radius, size[0] / 2 - radius])
            for (y = [-size[1] / 2 + radius, size[1] / 2 - radius])
                translate([x, y, 0])
                    cylinder(h = size[2], r = radius);
    }
}

module board_pod_envelope() {
    rounded_box(pcb_pod_size_mm, pcb_pod_corner_radius_mm);
}

module lower_rim() {
    translate([0, 0, -rim_height_mm])
        difference() {
            cylinder(h = rim_height_mm, d = outer_diameter_mm - 1.2);
            cylinder(h = rim_height_mm + 0.2,
                     d = inner_diameter_mm + (2 * rim_radial_width_mm));
        }
}

module finger_opening() {
    translate([0, 0, -rim_height_mm - 0.5])
        cylinder(h = shell_height_mm + rim_height_mm + 1.0,
                 d = inner_diameter_mm);
}

module battery_pocket() {
    translate(battery_center_mm)
        cube(battery_keepout_mm, center = true);
}

module sensor_cavity() {
    translate(sensor_cavity_center_mm)
        cube(sensor_cavity_mm, center = true);
}

module module_pocket() {
    translate(module_center_mm)
        cube(module_keepout_mm, center = true);
}

module pcb_tray_clearance() {
    translate(pcb_tray_center_mm)
        cube(pcb_tray_clearance_mm, center = true);
}

module top_component_clearance() {
    translate([0, 0, pcb_top_z_mm + 1.7])
        cube([pcb_size_mm[0] + 0.8,
              pcb_size_mm[1] - 3.0,
              shell_height_mm - pcb_top_z_mm - lid_top_skin_mm + 0.2],
             center = true);
}

module service_access_opening() {
    translate(service_access_center_mm)
        cube(service_access_opening_mm, center = true);
}

module service_fixture_keepout() {
    translate([service_access_center_mm[0] + 1.2,
               service_access_center_mm[1],
               service_access_center_mm[2] - 0.1])
        cube(service_fixture_keepout_mm, center = true);
}

module dome_switch_pocket() {
    translate(dome_switch_center_mm)
        cylinder(h = dome_pocket_depth_mm,
                 d = dome_pocket_diameter_mm,
                 center = true);
}

module dome_actuator_relief() {
    translate([dome_switch_center_mm[0],
               dome_switch_center_mm[1],
               shell_height_mm - 0.35])
        cylinder(h = 0.8, d = dome_actuator_relief_diameter_mm, center = true);
}

module battery_harness_channel() {
    translate(battery_harness_channel_center_mm)
        cube(battery_harness_channel_mm, center = true);
}

module battery_service_loop_relief() {
    translate(battery_service_loop_center_mm)
        cube(battery_service_loop_relief_mm, center = true);
}

module battery_lift_window() {
    translate(battery_lift_window_center_mm)
        cube(battery_lift_window_mm, center = true);
}
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

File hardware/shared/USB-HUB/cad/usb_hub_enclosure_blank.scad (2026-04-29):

// SPDX-License-Identifier: CERN-OHL-S-2.0
//
// First mechanical packet for the active USB-HUB direct-plug board.
// This captures the stepped PCB, shell-clamp holes, service access, and
// adjacent-port gauges from kicad/usb_hub.kicad_pcb. It is still a
// prototype-fit source, not measured mechanical evidence.
//
// Export modes:
//   enclosure
//   host_fit_coupon
//   clamp_alignment_gauge
//   service_hatch_reach_gauge
//   validation_set

$fn = 64;

board_outline_pts = [
    [0, 5.2],
    [14, 5.2],
    [14, 0],
    [54, 0],
    [54, 26],
    [14, 26],
    [14, 20.8],
    [0, 20.8]
];

board_thickness_mm = 1.6;
board_clearance_mm = 0.45;
wall_thickness_mm = 1.4;
bottom_floor_mm = 1.5;
top_lid_thickness_mm = 1.5;
lid_lip_depth_mm = 1.0;
top_component_clearance_mm = 5.3;
explode_gap_mm = 7.0;

// Board features copied from ../kicad/usb_hub.kicad_pcb.
body_shoulder_x_mm = 14;
board_rear_x_mm = 54;
shell_clamp_holes_mm = [[15.6, 6.6], [15.6, 19.4]];
shell_clamp_board_drill_mm = 1.4;
shell_clamp_screw_clearance_mm = 1.55;
shell_clamp_boss_od_mm = 3.6;
service_window_origin_mm = [17.0, 22.05];
service_window_size_mm = [34.2, 3.95];
service_hatch_clearance_mm = 0.25;
service_hatch_thickness_mm = 0.9;
antenna_keepout_origin_mm = [41.7, 5.3];
antenna_keepout_size_mm = [5.3, 15.4];

// Host-fit reference gauges. These are not passed/failed by CAD alone.
host_face_x_mm = 0;
host_insertion_zone_depth_mm = 14;
adjacent_port_pitch_mm = 14.0;
adjacent_usb_a_shell_width_ref_mm = 12.2;
adjacent_port_gauge_depth_mm = 18.0;

export_mode = "enclosure";
show_exploded_view = true;
show_reference_board = true;
show_service_hatch = true;
show_host_clearance_gauges = true;

quick_print_coupon_height_mm = 3.0;
quick_print_plate_thickness_mm = 1.2;
host_fit_coupon_depth_mm = 24.0;
clamp_alignment_gauge_depth_mm = 23.0;
validation_artifact_gap_mm = 11.0;

bottom_shell_height_mm =
    bottom_floor_mm + board_thickness_mm + top_component_clearance_mm;
assembled_lid_z_mm = bottom_shell_height_mm;
exploded_lid_z_mm = bottom_shell_height_mm + explode_gap_mm;

function lid_z() =
    show_exploded_view ? exploded_lid_z_mm : assembled_lid_z_mm;

module board_outline_2d(expand_mm = 0) {
    offset(delta = expand_mm)
        polygon(points = board_outline_pts);
}

module shell_prism(height_mm, expand_mm = 0) {
    // Do not let the printed shell protrude in front of the USB-A host face.
    intersection() {
        linear_extrude(height = height_mm)
            board_outline_2d(expand_mm);

        translate([host_face_x_mm,
                   -20,
                   -0.1])
            cube([board_rear_x_mm + expand_mm + 20,
                  26 + (2 * expand_mm) + 40,
                  height_mm + 0.2]);
    }
}

module front_slice_prism(height_mm, depth_mm, expand_mm = 0) {
    intersection() {
        shell_prism(height_mm, expand_mm);

        translate([host_face_x_mm,
                   -20,
                   -0.1])
            cube([depth_mm,
                  66,
                  height_mm + 0.2]);
    }
}

module screw_hole_stack(height_mm, z_start_mm = -0.1) {
    for (hole = shell_clamp_holes_mm) {
        translate([hole[0],
                   hole[1],
                   z_start_mm])
            cylinder(h = height_mm,
                     d = shell_clamp_screw_clearance_mm);
    }
}

module bottom_clamp_bosses() {
    for (hole = shell_clamp_holes_mm) {
        translate([hole[0],
                   hole[1],
                   0])
            cylinder(h = bottom_floor_mm,
                     d = shell_clamp_boss_od_mm);
    }
}

module top_compression_pads() {
    for (hole = shell_clamp_holes_mm) {
        translate([hole[0],
                   hole[1],
                   -top_component_clearance_mm + 0.05])
            cylinder(h = top_component_clearance_mm - 0.05,
                     d = shell_clamp_boss_od_mm);
    }
}

module host_fit_coupon() {
    shell_expand_mm = wall_thickness_mm + board_clearance_mm;

    union() {
        front_slice_prism(quick_print_coupon_height_mm,
                          host_fit_coupon_depth_mm,
                          shell_expand_mm);

        // Raised witness line: if this shoulder contacts the host before the
        // plug seats, the wider body is too close to the USB-A nose.
        translate([body_shoulder_x_mm - 0.2,
                   5.2 - shell_expand_mm,
                   quick_print_coupon_height_mm])
            cube([0.4,
                  15.6 + (2 * shell_expand_mm),
                  0.6]);

        // A shallow host-face datum keeps the coupon honest about x=0 without
        // creating a printed tongue meant to enter the USB port.
        translate([host_face_x_mm,
                   5.2 - shell_expand_mm,
                   quick_print_coupon_height_mm])
            cube([0.35,
                  15.6 + (2 * shell_expand_mm),
                  0.45]);
    }
}

module clamp_alignment_gauge() {
    difference() {
        union() {
            front_slice_prism(quick_print_plate_thickness_mm,
                              clamp_alignment_gauge_depth_mm,
                              0.25);

            for (hole = shell_clamp_holes_mm) {
                translate([hole[0],
                           hole[1],
                           0])
                    cylinder(h = quick_print_plate_thickness_mm + 0.55,
                             d = shell_clamp_boss_od_mm);
            }

            translate([body_shoulder_x_mm - 0.15,
                       5.2,
                       quick_print_plate_thickness_mm])
                cube([0.3,
                      15.6,
                      0.45]);
        }

        screw_hole_stack(quick_print_plate_thickness_mm + 0.95,
                         -0.2);
    }
}

module service_hatch_reach_gauge() {
    frame_margin_mm = 2.0;
    frame_origin = [
        service_window_origin_mm[0] - frame_margin_mm,
        service_window_origin_mm[1] - frame_margin_mm
    ];
    frame_size = [
        service_window_size_mm[0] + (2 * frame_margin_mm),
        service_window_size_mm[1] + (2 * frame_margin_mm)
    ];

    union() {
        difference() {
            translate([frame_origin[0],
                       frame_origin[1],
                       0])
                cube([frame_size[0],
                      frame_size[1],
                      quick_print_plate_thickness_mm]);

            translate([service_window_origin_mm[0],
                       service_window_origin_mm[1],
                       -0.1])
                cube([service_window_size_mm[0],
                      service_window_size_mm[1],
                      quick_print_plate_thickness_mm + 0.2]);

            // Spudger approach witness for the removable hatch notch.
            translate([service_window_origin_mm[0] + service_window_size_mm[0] - 3.0,
                       service_window_origin_mm[1] + service_window_size_mm[1] - 0.35,
                       -0.1])
                cylinder(h = quick_print_plate_thickness_mm + 0.2,
                         d = 1.8);
        }

        translate([0,
                   -(service_window_size_mm[1]
                     + frame_margin_mm
                     + validation_artifact_gap_mm),
                   0])
            service_hatch();
    }
}

module validation_set() {
    host_fit_coupon();

    translate([0,
               26 + (2 * (wall_thickness_mm + board_clearance_mm))
                   + validation_artifact_gap_mm,
               0])
        clamp_alignment_gauge();

    translate([0,
               26 + (2 * (wall_thickness_mm + board_clearance_mm))
                   + 40,
               0])
        service_hatch_reach_gauge();
}

module bottom_shell() {
    difference() {
        union() {
            difference() {
                shell_prism(bottom_shell_height_mm,
                            wall_thickness_mm + board_clearance_mm);

                translate([0,
                           0,
                           bottom_floor_mm])
                    shell_prism(bottom_shell_height_mm,
                                board_clearance_mm);
            }

            bottom_clamp_bosses();

            // Small connector-side floor shelf; the real load path is the
            // screw-clamped MH1/MH2 pair plus J1 shell tabs, not solder alone.
            translate([host_face_x_mm,
                       5.2 - board_clearance_mm,
                       bottom_floor_mm])
                cube([body_shoulder_x_mm + 0.8,
                      15.6 + (2 * board_clearance_mm),
                      0.7]);
        }

        screw_hole_stack(bottom_floor_mm + 0.2);
    }
}

module top_lid() {
    difference() {
        union() {
            shell_prism(top_lid_thickness_mm,
                        wall_thickness_mm + board_clearance_mm);
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

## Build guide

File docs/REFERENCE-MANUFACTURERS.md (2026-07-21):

<!-- SPDX-License-Identifier: CC-BY-SA-4.0 -->
# Reference Manufacturers

**Public knowledge. Not endorsement. No referral fees exist.**

This is a living doc of factories and services that have actually run
PowerFinger or PowerFinger-compatible designs at various volumes. The
purpose is to remove the "which factory in Huaqiangbei do I even talk to"
footgun for downstream entrants — to lower the activation energy for
someone who wants to ship a derivative or run a small batch for a care
facility, a school district, or an accessibility nonprofit.

## Disclaimer

> This document is documentation of public knowledge at specific
> timestamps. Factories change. MOQs change. Lead times change. Yields
> drift. **Verify with each vendor before placing orders.** No relationship,
> no endorsement, and no referral fees exist between the PowerFinger
> project and any listed vendor. Listings are not recommendations; they are
> records of what has been tried.

This disclaimer is load-bearing. The supply-chain misinformation risk if
this doc is treated as endorsement is real (see
`docs/scoping/LICENSE-REVISION-SCOPE.md` §5.2 risk 4). Treat it as a
starting point for due diligence, not the conclusion.

---

## How to Read This Document

Each tier has a table. Each row is a vendor that has run the design at the
listed volume. Each row includes:

- **Vendor** — name and primary URL
- **Last verified** — date the entry was last confirmed accurate. Entries
  more than 12 months unverified are visually flagged with `⚠️ STALE` so
  the reader does not mistake stale data for current data.
- **What was run** — which variant(s) and at what stage (rev, count)
- **MOQ** — minimum order quantity at last verification
- **Realized COGS** — actual landed cost per unit, if known. **Not the
  vendor's quote — the actual COGS after defects, shipping, customs, and
  any rework.** If only the quote is available, label as "quoted, not
  realized."
- **Lead time** — quoted vs. realized
- **Yield / defects** — defect rate and notes on failure modes
- **Notes** — operational quirks, communication channels, payment terms,
  IP-handling reputation, anything a future builder should know

Empty cells are honestly empty. Do not infer from absence; infer from data
or the absence of an entry entirely.

---

## Tier 1 — DIY (1 unit)

For builders making one device for themselves or one user.

### Vendor table

| Vendor | Last verified | What was run | MOQ | Realized COGS | Lead time | Yield | Notes |
|---|---|---|---|---|---|---|---|
| *(no entries yet)* | | | | | | | |

### Notes

- For one-off DIY, the relevant "vendors" are the component distributors
  (Digi-Key, Mouser, LCSC) and a 3D printer (personal or local maker
  space) for the shell. PCB fab at quantity 1 is best handled by JLCPCB
  or PCBWay's individual-order service, but neither has been run for
  PowerFinger yet.
- Tier 1 is the most permissive tier. The CERN-OHL-S 2.0 license imposes
  source-disclosure obligations only on conveyance (distribution outside
  your organization). One-off DIY for personal use is not conveyance and
  triggers no disclosure obligation. See
  `docs/NAMING-AND-COMPATIBILITY.md` §6.

---

## Tier 2 — Small Batch (25–500 units)

For care facilities, school districts, accessibility nonprofits, university
research labs, and prosumer makers who want to ship to a small population.

### Vendor table

| Vendor | Last verified | What was run | MOQ | Realized COGS | Lead time | Yield | Notes |
|---|---|---|---|---|---|---|---|
| Seeed Studio Fusion + Propagate | *not yet run* | Candidate for `USB-HUB` first PCB/assembly quote, with `R30-OLED-NONE-NONE` only as a DFM/pre-fab review annex | TBD | TBD | TBD | TBD | **Placeholder. No quote or batch has been run yet.** Current packet: [`docs/sensors-converge-2026/SHENZHEN-SEEED-QUOTE-PACKET.md`](sensors-converge-2026/SHENZHEN-SEEED-QUOTE-PACKET.md). First reply evidence must land under `docs/sensors-converge-2026/factory-replies/` and pass the response-capture update gate before this row changes. Use the send-now path for `USB-HUB`; treat ring materials as annex-only DFM/pre-fab review until board-house output constraints and physical fit/stackup evidence close. |
| JLCPCB / EasyEDA ecosystem | *not yet run* | Candidate fallback for active packet PCB fab/assembly only; enclosure/serviceability still needs separate handling | TBD | TBD | TBD | TBD | **Placeholder. No quote or batch has been run yet.** Listed because `PCB1` BOM notes already name JLCPCB/PCBWay-style prototype rigid PCB sourcing. Do not record as PowerFinger-proven until an actual quote or run exists. |
| PCBWay | *not yet run* | Candidate fallback for active packet PCB fab/assembly and prototype mechanical review | TBD | TBD | TBD | TBD | **Placeholder. No quote or batch has been run yet.** Listed for Shenzhen scoping only. Any row update must separate quoted PCB/assembly cost from realized landed COGS and defects. |
| Local Bao'an / Longgang prototype house | *not yet identified* | In-person DFM/prototype-house fallback for ring shell/board serviceability questions | TBD | TBD | TBD | TBD | **Placeholder class, not a vendor.** Fill with a named shop only after contact details, quote scope, communication channel, payment terms, and license/source-return posture are known. |

### Notes

- At this tier, source-disclosure obligations under CERN-OHL-S 2.0
  activate on conveyance. Care facilities distributing to residents are
  conveying; internal use within a single facility may not be (consult
  counsel).
- Documentation expectations rise sharply at this tier. Each unit shipped
  needs assembly date, firmware version, and a path back to the
  certification UID (when OSHWA cert exists for the variant).

---

## Tier 3 — Mid-Batch (500–10,000 units)

For accessibility-focused commercial entrants, regional distributors, and
larger nonprofit deployments.

### Vendor table

| Vendor | Last verified | What was run | MOQ | Realized COGS | Lead time | Yield | Notes |
|---|---|---|---|---|---|---|---|
| *(no entries yet)* | | | | | | | |

### Notes

- At this tier, regulatory compliance (FCC for US, CE/UKCA/RED for EU/UK,
  IC for Canada) is a hard requirement. `docs/REGULATORY-PRESCAN.md`
  documents the prescan; actual certification is the entrant's
  responsibility.
- Commercial entrants at this tier should pursue OSHWA Certified status
  per variant. See `docs/IP-STRATEGY.md` Action Items for the submission
  order.
- IP handling becomes material at this scale. Vendors with a track record
  of respecting CERN-OHL-S 2.0 reciprocity (publishing modified source on
  conveyance) should be preferred. Vendors known to ignore copyleft
  obligations should be flagged.

---

## Tier 4 — Large Batch (10,000+ units)

For consumer-product entrants and large institutional deployments
(insurance-reimbursed assistive devices, large hospital networks, etc.).

### Vendor table

| Vendor | Last verified | What was run | MOQ | Realized COGS | Lead time | Yield | Notes |
|---|---|---|---|---|---|---|---|
| *(no entries yet)* | | | | | | | |

### Notes

- At this tier, MCU migration to nRF52840 should be evaluated for the
  3–5x battery life improvement. See `docs/NRF52840-MIGRATION.md`.
- Consumer-product framing introduces FDA / EU MDR considerations if
  the device is positioned as a medical device. The project's posture is
  that PowerFinger is an assistive HID device, not a medical device. See
  `docs/scoping/LICENSE-REVISION-SCOPE.md` §4.5 and `docs/REGULATORY-PRESCAN.md`.
- Tier 4 entrants should also evaluate OIN / Unified Patents membership
  for patent-litigation defensive coverage. See `docs/IP-STRATEGY.md`
  Defensive Alliances section.

---

## What Goes In a New Entry

When you (anyone — maintainer, contributor, downstream productizer) add a
vendor to this document:

1. Open a PR adding the row to the appropriate tier's table.
2. Fill **Last verified** with today's date in `YYYY-MM-DD` format.
3. Fill **Realized COGS** only with actual landed cost; quoted-only data
   should be marked `(quoted)` and treated as approximate.
4. Add operational notes that would have saved you a week if you'd had
   them when you started — payment terms, communication channels,
   common failure modes, IP-handling reputation, language barriers.
5. Be honest about defects and yield. The doc's value is honesty.

---

## Maintenance

This document depends on contributors keeping entries current. The
**Last verified** column drives this:

- Entries verified within the last 12 months: trusted as current.
- Entries 12–24 months unverified: prefix with `⚠️ STALE — last verified
  YYYY-MM-DD` and treat as historical reference only.
- Entries more than 24 months unverified: candidates for removal unless
  someone re-verifies and updates the timestamp.

Entries are not deleted when vendors disappear. The historical record is
useful — it tells future builders which approaches have been tried and
why they didn't continue. Mark abandoned vendors with `🪦 ABANDONED —
[reason]` rather than removing.

---

## Cross-References

- [`docs/NAMING-AND-COMPATIBILITY.md`](NAMING-AND-COMPATIBILITY.md) —
  conveyance vs. internal modification under CERN-OHL-S 2.0.
- [`docs/CONFORMANCE.md`](CONFORMANCE.md) — conformance criteria for
  ecosystem participants.
- [`docs/IP-STRATEGY.md`](IP-STRATEGY.md) — IP defense strategy and OSHWA
  cert action items.
- [`docs/REGULATORY-PRESCAN.md`](REGULATORY-PRESCAN.md) — regulatory
  compliance prescan.
- [`docs/CONSUMER-TIERS.md`](CONSUMER-TIERS.md) — consumer-product Standard
  / Pro tier definitions.
- [`docs/NRF52840-MIGRATION.md`](NRF52840-MIGRATION.md) — MCU migration
  analysis for consumer-product generation.
- [`docs/VENDOR-VERIFICATION.md`](VENDOR-VERIFICATION.md) — component
  sourcing verification (sibling concept at the part level rather than
  factory level).

---

*This document is part of the PowerFinger documentation set, licensed under
CC-BY-SA 4.0. It is not legal advice. The project consists of unincorporated
contributors, not a legal entity. No vendor relationships, endorsements, or
referral fees exist.*

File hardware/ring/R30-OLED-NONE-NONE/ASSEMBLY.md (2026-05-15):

<!-- SPDX-License-Identifier: CERN-OHL-S-2.0 -->
# R30-OLED-NONE-NONE Assembly Baseline

This is the pre-CAD assembly baseline for the first optical ring hardware drop.
It defines the non-destructive build order the design must support. It is not a
claim that the package is already mechanically validated.

## Required Tools

- ESD-safe tweezers
- Fine-tip soldering iron and hot-air rework station
- Non-marring spudger
- Flush cutters
- Calipers
- Isopropyl alcohol for cleanup and removable-adhesive release

## Allowed Consumables

- Removable battery adhesive tabs or thin double-sided adhesive that can be
  released with IPA and gentle lift
- Threadlocker only on removable mechanical fasteners, not on service seams
- Opaque sealant only where it does not block later sensor or battery service

## Not Allowed

- Potting compound
- Cyanoacrylate or epoxy bridging the primary service seam
- Battery adhesive that requires bending or puncturing the cell to remove
- Service pads or fixture access acting as the sole mechanical retention feature

## Intended Assembly Order

1. Verify the selected LiPo has integrated PCM, documented size, and UN 38.3
   paperwork before shell fit is finalized.
2. Populate the PCB or carrier assembly, leaving the antenna keep-out free of
   shields, screws, carbon fiber, or metal trim.
3. Install the optical sensor and matched lens stack so the optical path is
   mechanically constrained rather than glue-positioned by luck.
4. Mount the dome click so replacement does not require removing the battery.
5. Install the battery using removable adhesive and route leads so cell removal
   does not require de-soldering the USB connector first.
6. Close the shell with a reversible seam: screws, snaps, or another clearly
   re-openable method.
7. Apply replaceable glide pads last so worn pads can be swapped independently
   of the shell and electronics.

## Assembly Record To Capture

- Actual battery dimensions and supplier
- Sensor and lens part numbers used
- Shell size parameters used for the wearer
- Closure method used
- Any adhesive used near the battery, lens, or service seam

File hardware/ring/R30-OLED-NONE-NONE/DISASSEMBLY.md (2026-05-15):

<!-- SPDX-License-Identifier: CERN-OHL-S-2.0 -->
# R30-OLED-NONE-NONE Disassembly Baseline

This document defines the non-destructive teardown path the first optical ring
hardware drop must preserve.

## Safety First

- Disconnect USB power before opening the ring.
- If the cell is swollen, hot, punctured, or smells of solvent, stop and treat
  it as a battery incident rather than a normal repair.
- Do not pry against the pouch cell.

## Intended Removal Order

1. Remove glide pads or exterior trim pieces that block the primary service seam.
2. Open the shell using its designed seam, not by cutting or cracking the body.
3. Isolate and remove the battery before high-heat rework near the charger or
   USB connector.
4. Remove the PCB or module assembly as a unit where possible.
5. Remove the optical sensor and lens stack only after their orientation and gap
   features are documented.
6. Remove the dome click element without destroying the shell seat.

## Replacement Expectations

- Battery replacement must not require shell destruction.
- Glide pads must be replaceable wear items.
- Service-pad or fixture-interface repair must not require discarding the
  entire shell.
- Sensor and lens must remain field-replaceable even if fine-pitch rework is
  required.

## Failure Conditions

If teardown requires cutting the shell, peeling a battery from permanent epoxy,
or sacrificing the sensor mount to reach the cell, the design fails the current
repairability baseline.

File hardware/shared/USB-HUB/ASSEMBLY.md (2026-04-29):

<!-- SPDX-License-Identifier: CERN-OHL-S-2.0 -->
# USB-HUB Assembly Baseline

This is the minimum non-destructive assembly order for the first hub hardware
drop.

## Required Tools

- ESD-safe tweezers
- Fine-tip soldering iron and hot-air rework station
- Flush cutters
- Calipers
- Non-marring spudger

## Critical Build Constraints

- USB connector must have mechanical support beyond solder pads alone.
- Enclosure must reopen for switch, LED, and connector repair.
- ESP32-S3 antenna keep-out must remain unobstructed by metal shells or hardware.
- The stepped direct-plug board must be clamped through `MH1` / `MH2`; do not
  substitute adhesive, heat-shrink, or potting for connector retention.
- Service pads and the `SW1` pad-actuated `BOOT_N` footprint must remain
  reachable through the service hatch after the lid is installed.

## Intended Assembly Order

1. Populate the PCB, paying special attention to USB data routing and connector
   reinforcement features.
2. Install the status LED and boot/reset control so they remain accessible for
   service.
3. Fit the stepped PCB into the bottom shell with the USB-A nose at the host
   face and the wider body seated behind the `x=14 mm` shoulder.
4. Align the enclosure clamp hardware through `MH1` / `MH2`; tighten only
   enough to prevent connector rocking without bowing the PCB.
5. Install the lid and confirm the removable service hatch exposes `TP1`-`TP9`
   plus `SW1`.
6. Capture the exact connector style used so future replacements match the shell.

## Assembly Record To Capture

- Connector type and supplier
- Enclosure material and retention method
- Clamp hardware or printed-pin choice used at `MH1` / `MH2`
- Adjacent-port host fit observations with the stepped USB-A direct-plug body
- Any reinforcement used around the connector beyond the packeted shell geometry

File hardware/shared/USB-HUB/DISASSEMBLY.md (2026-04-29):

<!-- SPDX-License-Identifier: CERN-OHL-S-2.0 -->
# USB-HUB Disassembly Baseline

This is the teardown baseline for the shared hub accessory.

## Intended Removal Order

1. Remove the service hatch with a non-marring spudger if pad access is needed.
2. Remove the reversible clamp hardware at `MH1` / `MH2`.
3. Open the enclosure at its designed seam.
4. Lift the PCB from the wider body first; do not pry on the USB connector shell
   or use the USB-A nose as a lever.
5. Service the switch, LED, service pads, or connector individually where
   possible.

## Replacement Expectations

- USB connector replacement must not require discarding the enclosure.
- Switch and LED repairs should not require cutting the board out of the shell.
- The enclosure should survive at least one routine service cycle.
- `MH1` / `MH2` clamp hardware should be replaceable without changing the PCB.

## Failure Conditions

If the enclosure must be cracked open or the connector has no practical repair
path short of discarding the board, the design fails this baseline.

If the service hatch cannot expose `EN`, `BOOT_N`, UART, power, and ground pads
without removing the whole board, the enclosure fails the active-lane recovery
baseline.

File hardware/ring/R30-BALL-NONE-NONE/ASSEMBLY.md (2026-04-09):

<!-- SPDX-License-Identifier: CERN-OHL-S-2.0 -->
# R30-BALL-NONE-NONE Assembly Baseline

This is the minimum non-destructive assembly order the first ball+Hall ring
design must support.

## Required Tools

- ESD-safe tweezers
- Fine-tip soldering iron and hot-air rework station
- Non-marring spudger
- Magnification suitable for Hall-sensor orientation checks
- Calipers

## Critical Build Constraints

- The ball must be removable for cleaning and replacement.
- The roller and magnet stack must be positively located, not free-floating on
  adhesive alone.
- Battery installation must still use removable adhesive and a reopenable seam.
- Hall sensors must be installed with known polarity and channel mapping.

## Intended Assembly Order

1. Verify battery paperwork and physical envelope before locking the shell.
2. Populate the PCB or carrier assembly, especially the Hall sensors, with
   orientation documented for later service.
3. Assemble the roller and magnet subcomponents so a failed roller can be
   swapped without replacing the whole shell.
4. Install the ball socket and confirm the ball can be inserted and removed
   without cracking the shell.
5. Install the click element so click-service does not require disturbing the
   tracking ball path.
6. Install the battery with removable adhesive and route wiring clear of the
   ball cavity and service seam.
7. Close the shell with a reversible seam.

## Assembly Record To Capture

- Ball material and source
- Roller spindle and magnet dimensions
- Hall sensor orientation map
- Final ball protrusion and free-spin notes
- Closure method and any adhesive used

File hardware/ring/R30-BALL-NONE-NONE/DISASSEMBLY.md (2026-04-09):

<!-- SPDX-License-Identifier: CERN-OHL-S-2.0 -->
# R30-BALL-NONE-NONE Disassembly Baseline

This teardown path is part of the publication baseline for the ball+Hall ring.

## Safety First

- Disconnect USB power before opening the ring.
- Remove the battery before prolonged heat or solvent exposure.
- Do not allow loose magnets or steel balls near the pouch cell during service.

## Intended Removal Order

1. Open the shell at the primary service seam.
2. Remove the battery before extracting the ball and roller hardware.
3. Remove the ball as a discrete wear/cleaning component.
4. Remove rollers and magnets without cutting the shell or deforming the socket.
5. Remove PCB or Hall-sensor assembly after the moving parts are documented.
6. Remove the dome click without destroying its seat.

## Replacement Expectations

- Ball and rollers are wear items and should be replaceable.
- A single failed Hall channel should not require shell destruction.
- Battery replacement must remain independent from the ball socket.

## Failure Conditions

If the only practical way to clean debris from the ball path is to crack the
shell, or if battery replacement requires disturbing permanently bonded roller
assemblies, the design fails this baseline.

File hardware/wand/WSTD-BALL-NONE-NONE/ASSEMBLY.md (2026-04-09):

<!-- SPDX-License-Identifier: CERN-OHL-S-2.0 -->
# WSTD-BALL-NONE-NONE Assembly Baseline

This is the minimum serviceable assembly order for the first wand hardware drop.

## Required Tools

- ESD-safe tweezers
- Fine-tip soldering iron and hot-air rework station
- Calipers
- Non-marring spudger
- Small vise or soft jaws for tube/end-cap handling

## Critical Build Constraints

- Tip module and rear end cap must be separately removable.
- Battery replacement must not require destroying the tip module.
- Barrel switch replacement must not require crushing or permanently deforming
  the tube body.
- The ball path must remain cleanable.

## Intended Assembly Order

1. Verify the protected LiPo cell size and route it to a serviceable battery bay.
2. Populate the rigid PCB or carrier, documenting switch and Hall-sensor
   orientation.
3. Assemble the tip module so the ball and roller system can be removed for
   cleaning or replacement.
4. Install the barrel switch with a retention method that remains serviceable.
5. Install the battery using removable adhesive or a removable cradle.
6. Close the rear USB-C end cap with a reversible retention method.
7. Record final mass, balance point, and any material choices that affect skin
   comfort or tremor damping.

## Assembly Record To Capture

- Tube material and wall thickness
- Tip-module retention method
- Switch model actually used
- Battery dimensions and supplier
- Closure methods at tip and rear cap

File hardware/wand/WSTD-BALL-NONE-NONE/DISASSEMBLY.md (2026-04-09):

<!-- SPDX-License-Identifier: CERN-OHL-S-2.0 -->
# WSTD-BALL-NONE-NONE Disassembly Baseline

This teardown path defines the minimum replaceability standard for the wand.

## Safety First

- Disconnect USB power before opening the wand.
- Remove the battery before high-heat rework near the charge path.
- Do not use the tube body as a pry bar against the pouch cell.

## Intended Removal Order

1. Open the rear service path and remove the battery first.
2. Remove the tip module as a discrete assembly.
3. Remove the ball and roller components for cleaning or replacement.
4. Remove the barrel switch without cutting the body tube.
5. Remove the electronics carrier or PCB after the mechanical orientation is documented.

## Replacement Expectations

- Tip wear should not require replacing the entire wand body.
- The battery should be replaceable independently of the tip module.
- A failed barrel switch should be a routine repair, not a body write-off.

## Failure Conditions

If teardown requires cutting the tube, forcing bonded end caps, or destroying
the tip module to replace the battery or switch, the design fails this baseline.

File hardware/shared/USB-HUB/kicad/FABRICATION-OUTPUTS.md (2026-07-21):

<!-- SPDX-License-Identifier: CERN-OHL-S-2.0 -->
# USB-HUB Fabrication Output Review

This note records the local fabrication-output proof for the DRC-clean routed
USB-HUB first-board KiCad source. The generated files are intentionally under
`build-kicad/` and are not checked in.

This is not physical hardware evidence. It does not prove connector retention,
adjacent-port clearance, host insertion/removal behavior, enclosure fit,
service-hatch reach, RF behavior, yield, realized COGS, or factory acceptance.

Use `BOARD-HOUSE-OUTPUT-CONSTRAINTS.md` to turn these generated outputs into
explicit prototype-house / Seeed-style intake questions for the active hub
quote path.

## Current Local Output

Output directory:
`build-kicad/USB-HUB/fabrication-review/`

Review archive:
`build-kicad/USB-HUB/usb-hub-fabrication-review.zip`

Archive SHA-256:
`c72cd55be079671a1adc68b89a7a250ed81e8175a9c4a179ebf1228098672432`

Generated output classes:

| Class | Files | Notes |
|---|---|---|
| Gerbers | 10 | `F.Cu`, `B.Cu`, paste, silkscreen, mask, `Edge.Cuts`, and Gerber job file |
| Drill | 5 | Split PTH/NPTH Excellon plus Gerber drill maps and drill report |
| Assembly review | 3 | Position CSV plus active-BOM/POS review CSV and markdown report; no warning-bearing KiCad schematic BOM is used |

The drill report records a two-layer copper stack (`F.Cu`, `B.Cu`), 25 plated
through holes, and 4 unplated through holes.

## Commands

Run the KiCad verifier first:

```bash
scripts/verify-firmware-local.sh --kicad-only
```

Generate the review outputs:

```bash
scripts/generate-usb-hub-fabrication-review.py
```

The generator runs KiCad Gerber, drill, and POS exports, merges the POS export
with `hardware/bom/USB-HUB.csv`, writes the assembly review, and creates the
review archive.

## Review Caveats

- `scripts/generate-usb-hub-fabrication-review.py` intentionally avoids the
  KiCad schematic BOM export and merges `hardware/bom/USB-HUB.csv` with the
  KiCad POS export instead. This preserves board refs such as `C1A`, `C1B`,
  `R1A`, and `R1B` while keeping the source-controlled active BOM as the quote
  contract.
- The generated active-BOM/POS review has no open rows. `C1A`/`C1B` map to the
  active BOM's two-count `C1` line, `R1A`/`R1B` map to the active BOM's
  two-count `R1` line, `C5`/`C6` are deliberate no-BOM DNI shunt-cap
  placeholders, and `TP1`-`TP9` are deliberate no-BOM service/test pads.
- `PCB1` and `ENCL1` remain active BOM rows without KiCad assembly placements
  because they are the board and enclosure deliverables, not sourced SMT/THT
  placements.
- The generated outputs are suitable for local review of the DRC-clean source
  packet and for first board-house intake. They are not proof that the hub can
  be built without connector-retention and host-clearance evidence.
- Generated KiCad timestamp fields are normalized to fixed values, and the
  review archive uses deterministic ZIP metadata, so repeated runs of the same
  source packet can be compared by hash.

## File Hashes

| SHA-256 | File |
|---|---|
| `7ec7ce5c575900a99c1fc7b870030caa6b71841f194a7b015f00eae5c0f76e20` | `gerbers/usb_hub-F_Cu.gtl` |
| `f64fc33dc8a6ace808db69bf5e639b5afbc22eb1f5d40dfa16a0fa483ea93def` | `gerbers/usb_hub-B_Cu.gbl` |
| `58c042ac4c386b823d7a63b8eb4668569728dc9a8b92bf13986a465060226229` | `gerbers/usb_hub-F_Paste.gtp` |
| `e2dbc8ab647495ce92e66bb20b3f08866e83f4d75bacaf7e21d4e8b212d57947` | `gerbers/usb_hub-B_Paste.gbp` |
| `673f4cd8453bb5344787e80b13030b90c74e879c3ef21bc3967b8557671147d9` | `gerbers/usb_hub-F_Silkscreen.gto` |
| `8887ab97fe9d61673ad474881a0510648187c471a8aab9f8cc77bdc03dfefdf5` | `gerbers/usb_hub-B_Silkscreen.gbo` |
| `37d3c7a1f5dea17a52ecf62d924b5cc7f966c34fb504973634373cb786bec036` | `gerbers/usb_hub-F_Mask.gts` |
| `30c9c3ccd725104e876ccf1b3b4bcf2ad9801b80f6ee19d68855be0b9874cd82` | `gerbers/usb_hub-B_Mask.gbs` |
| `eb4c0115734d8ee4db719e8d044bed0ff307e58b00fcf409c867f5917a4f2c64` | `gerbers/usb_hub-Edge_Cuts.gm1` |
| `8be44af677e374c4eb5ccf2acab509193501964872d8bc89aa8078e90e48f7ca` | `gerbers/usb_hub-job.gbrjob` |
| `24fe9660a0d54fa90893875895a18fdf6dbc046a31bfcb63be17e50fd303dffb` | `drill/usb_hub-PTH.drl` |
| `1ebc9f7c691f06ae8301a36207d9239e5fb763e5fa090bd7b9317c54f1995b32` | `drill/usb_hub-NPTH.drl` |
| `f414b7f44a83bf0fb8544272d62c6b846ded00a448a08a4dbf6c1e962365bcf5` | `drill/usb_hub-PTH-drl_map.gbr` |
| `b357b4cfa5db0ad50a9039c507e943787e5d677e64406e55fa5d4baaf3acaabf` | `drill/usb_hub-NPTH-drl_map.gbr` |
| `e9f366a98dd9d6c2510bbdfcaaae50ff480d710273e2135ba27ab353ebfa0741` | `drill/usb_hub-drill-report.txt` |
| `e0887a045ccde230de036592fb4a1bad88aea6139d625a0c85ba46683b4f9338` | `assembly/usb_hub-pos.csv` |
| `936d16e69f6d6cfd46a6c306d1764a38ffe3570c16ee737deb0740cb3a94db3f` | `assembly/usb_hub-active-bom-pos-review.csv` |
| `b806f5e5e370a9b678925b6676128f60fc24b42decf9d6c06d4a86f47a9d438c` | `assembly/usb_hub-active-bom-pos-review.md` |

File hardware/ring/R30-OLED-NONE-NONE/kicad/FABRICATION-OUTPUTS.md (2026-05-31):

<!-- SPDX-License-Identifier: CERN-OHL-S-2.0 -->
# R30-OLED-NONE-NONE Fabrication Output Review

This note records the local fabrication-output proof for the DRC-clean routed
R30 first-board KiCad source. The generated files are intentionally under
`build-kicad/` and are not checked in.

This is not physical hardware evidence. It does not prove stackup height,
focal distance, RF behavior, service access, click feel, battery replacement,
yield, realized COGS, or factory acceptance.

Use `BOARD-HOUSE-OUTPUT-CONSTRAINTS.md` to turn these local generated outputs
into explicit prototype-house / Seeed-style intake questions before asking for
a ring PCB fab or assembly quote.

## Current Local Output

Output directory:
`build-kicad/R30-OLED-NONE-NONE/fabrication-review/`

Review archive:
`build-kicad/R30-OLED-NONE-NONE/r30-oled-none-none-fabrication-review.zip`

Archive SHA-256:
`0dd63a2361fecc7fd9870917a8fb1c3dbeec75227a1099f392a53a230516c52c`

Generated output classes:

| Class | Files | Notes |
|---|---|---|
| Gerbers | 12 | `F.Cu`, `In1.Cu`, `In2.Cu`, `B.Cu`, paste, silkscreen, mask, `Edge.Cuts`, and Gerber job file |
| Drill | 5 | Split PTH/NPTH Excellon plus Gerber drill maps and drill report |
| Assembly review | 3 | Position CSV plus active-BOM/POS review CSV and markdown report; no warning-bearing KiCad schematic BOM is used |

The drill report records a four-layer copper stack (`F.Cu`, `In1.Cu`,
`In2.Cu`, `B.Cu`), 40 plated through holes, and 0 unplated through holes.

## Commands

Run the KiCad verifier first:

```bash
scripts/verify-firmware-local.sh --kicad-only
```

Generate the review outputs:

```bash
mkdir -p \
  build-kicad/R30-OLED-NONE-NONE/fabrication-review/gerbers \
  build-kicad/R30-OLED-NONE-NONE/fabrication-review/drill \
  build-kicad/R30-OLED-NONE-NONE/fabrication-review/assembly

kicad-cli pcb export gerbers \
  --output build-kicad/R30-OLED-NONE-NONE/fabrication-review/gerbers \
  --layers F.Cu,In1.Cu,In2.Cu,B.Cu,F.Paste,B.Paste,F.Silkscreen,B.Silkscreen,F.Mask,B.Mask,Edge.Cuts \
  hardware/ring/R30-OLED-NONE-NONE/kicad/r30_oled_none_none.kicad_pcb

kicad-cli pcb export drill \
  --output build-kicad/R30-OLED-NONE-NONE/fabrication-review/drill \
  --format excellon \
  --excellon-units mm \
  --excellon-zeros-format decimal \
  --excellon-separate-th \
  --generate-map \
  --map-format gerberx2 \
  --generate-report \
  --report-path build-kicad/R30-OLED-NONE-NONE/fabrication-review/drill/r30_oled_none_none-drill-report.txt \
  hardware/ring/R30-OLED-NONE-NONE/kicad/r30_oled_none_none.kicad_pcb

scripts/generate-r30-assembly-review.py

cd build-kicad/R30-OLED-NONE-NONE/fabrication-review
zip -r ../r30-oled-none-none-fabrication-review.zip gerbers drill assembly
```

## Review Caveats

- `scripts/generate-r30-assembly-review.py` intentionally avoids the KiCad
  schematic BOM export and merges `hardware/bom/R30-OLED-NONE-NONE.csv` with
  the KiCad POS export instead. This preserves board refs such as `C1A`, `R2A`,
  and `TP_VBAT` without `?` suffixes.
- The source-controlled active BOM contract remains
  `hardware/bom/R30-OLED-NONE-NONE.csv`. The generated active-BOM/POS review has
  no open rows: board-real populated refs match placements, `Q1` plus
  `TP_CHRG`/`TP_MOT`/`TP_RST`/`TP_VBAT`/`TP_VBUS` are deliberate qty-0
  service/copper placements, `LED1` is an unplaced qty-0 fallback, and the
  remaining no-placement rows are off-board/mechanical items (`ANT1`, `BT1`,
  `LENS1`, `PAD1`, `PCB1`, `RIM1`, `SHELL1`).
- A Gerber command with `--subtract-soldermask --check-zones` crashed locally
  with KiCad CLI `10.0.2` / macOS Swift `Array index out of range`. The retained
  command omits those options and generated the listed outputs successfully.
- The generated outputs are suitable for local review of the DRC-clean source
  packet, not as proof that the ring should be quoted or built before physical
  fit and stackup evidence is recorded.

## File Hashes

| SHA-256 | File |
|---|---|
| `7a69d08d588c3d44183a9fe5ad95af7bee1a6bc00e66459178d0e6ac655014ec` | `gerbers/r30_oled_none_none-F_Cu.gtl` |
| `5d08c319d83ca1d450be078c8690490d21bbcc64fd5f66d180df0d6fbf608181` | `gerbers/r30_oled_none_none-In1_Cu.g1` |
| `a36a34270c4f71c391132e0446365709ca56d4121f1507c121573e84ceb1ba36` | `gerbers/r30_oled_none_none-In2_Cu.g2` |
| `ed4bc973d04563406b48429f22f39a1d862c53e020205b991463edf2145c54f9` | `gerbers/r30_oled_none_none-B_Cu.gbl` |
| `d4bb34d897344d2a1c9cf54883423748486b31fa3e82a897e61cf559d2b15da8` | `gerbers/r30_oled_none_none-F_Mask.gts` |
| `ee1b4df2383b1e6474bba8e991bf75c026a41a96597ee5adfcd59c1ccce1bbbc` | `gerbers/r30_oled_none_none-B_Mask.gbs` |
| `2c47b0ad803bf19b074de4e61c7d7b84a7b2d43f6e4b559ebc05785c8a877418` | `gerbers/r30_oled_none_none-F_Paste.gtp` |
| `b91aa013a68ecf566078f226441bc6e51543f68688e6865e997bae917bc47935` | `gerbers/r30_oled_none_none-B_Paste.gbp` |
| `04f520ae80d33f3d1434645152f5711b201bc04e0a1166fc3f3f9bf047c00d33` | `gerbers/r30_oled_none_none-F_Silkscreen.gto` |
| `509620e1aea6c0706672587a6c2684f9fdfee3206186b9af87c187a4fa0e11e5` | `gerbers/r30_oled_none_none-B_Silkscreen.gbo` |
| `378ef1379fddcf141dc49511185ca8cff32fa754f0bef1cc5c976eef02a03d39` | `gerbers/r30_oled_none_none-Edge_Cuts.gm1` |
| `47d14b7cb35b6e3ce0f55f3280d9711a942f4952fcab1c0d44bfe24c7866784d` | `gerbers/r30_oled_none_none-job.gbrjob` |
| `7bc2ab58fdb86153e3e2fcde93aacc57ad913a992498dcfc7c0818777f70a209` | `drill/r30_oled_none_none-PTH.drl` |
| `af0aa0b41bf6f4ef622c595b328159efc710b0152bc506aafcba8f4187a22290` | `drill/r30_oled_none_none-NPTH.drl` |
| `b365d113e77d8e8a164867600d27a0f4465b71cb21e1d33577e6c03e8d60c09c` | `drill/r30_oled_none_none-PTH-drl_map.gbr` |
| `ad3b9db331a954e5ae99429874c1a536cbabf4ab1967ae98840c3d95a6ea57e8` | `drill/r30_oled_none_none-NPTH-drl_map.gbr` |
| `7e05bbb486ec6e016c19d9719037613edc13649e723b9faaa66b6f22a49c66f2` | `drill/r30_oled_none_none-drill-report.txt` |
| `574c2af18e1c92f41e4ea164cd6bfd554a9a61d4e9c19c1cfbc0738ee30a6b72` | `assembly/r30_oled_none_none-pos.csv` |
| `ce69888d2e9718128bba37fa1b6c14a6e7ebd9ec885c0cfe78c57c3ab3a3dc88` | `assembly/r30_oled_none_none-active-bom-pos-review.csv` |
| `c8c3fe7b1dd44e7d0db0159b3101019e319af383abd6ce2a6b74f69c1081c778` | `assembly/r30_oled_none_none-active-bom-pos-review.md` |

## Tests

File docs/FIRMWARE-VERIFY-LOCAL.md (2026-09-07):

# Local Verification

PowerFinger verification runs locally. SDK installation and initial dependency
retrieval require network access; device operation remains fully offline. The
public entrypoint is `scripts/verify-firmware-local.sh`; it delegates to the
standard-library orchestrator in `scripts/verify_firmware_local.py`. Every
run writes a JSON report and per-stage log files under an ignored build directory.
Commands and tests have timeouts; output is streamed to disk rather than
accumulated in the agent's context.

## Default

```bash
scripts/verify-firmware-local.sh
```

The default selection is verifier regression tests, host CTests, Ruby contract
checks, Python operator self-tests, the companion Node protocol test, a separate
ASan+UBSan host CTest build, the active `r30-oled-none-none` ring profile, `hub`,
and strict KiCad 10 ERC/DRC for both active packets. Failures are collected across
independent stages; missing prerequisites fail explicitly and dependent checks
are recorded as skipped. Such a run cannot pass.

The report records source revision/dirty state, declared and observed tool
versions, selections, statuses, reasons, and artifact paths. A dirty source
tree is recorded for review and does not by itself turn green checks red.
Each invocation replaces any previous report with a `running` result before
checking anything, then atomically writes the final result. Interrupted or
unfinished runs must not be treated as passes.

## Modes

```bash
scripts/verify-firmware-local.sh --fast
scripts/verify-firmware-local.sh --firmware-only ring pen puck hub
scripts/verify-firmware-local.sh --all
scripts/verify-firmware-local.sh --doctor
scripts/verify-firmware-local.sh --hardware-only
scripts/verify-firmware-local.sh --hardware-report-only
```

`--fast` (also the compatibility alias `--host-tests-only`) runs verifier tests,
host, contracts, operator, and companion checks only. `--firmware-only` excludes all
host and hardware checks. `--all` adds the generic development ring, pen, and
puck to the firmware selection. The `ring` selector means the active R30
profile; use `ring-generic` explicitly for the fake-sensor development build.
`--doctor` performs prerequisite and pinned-SDK checks without builds.
`--hardware-only` requires KiCad and passes only when both packets have valid
zero-finding JSON reports. `--hardware-report-only` records findings for
inspection but always returns nonzero and never reports `pass`; it is not
verification. `--with-kicad` and `--kicad-strict` are retained aliases for
adding strict hardware checks, and `--kicad-only` aliases `--hardware-only`.
Contradictory modes are rejected.

Use `--report PATH` to choose the JSON report location. Use
`POWERFINGER_IDF_BUILD_ROOT` to relocate ESP-IDF build outputs; SDKCONFIG files
remain inside the selected private `build-idf/<sdk-commit>/verify/<profile>/` directory and are resolved
from committed defaults, so an ignored `firmware/<project>/sdkconfig` cannot
silently select a previous session's configuration.

## SDK build candidate

`toolchains/esp-idf-local.json` is authoritative: ESP-IDF `v6.1`, commit
`fff9895c82d744c7237be8847347bdd1b07c6643`, with `esp32c3` and `esp32s3`
targets. The verifier and setup script consume that same manifest. The committed
hub `dependencies.lock` records the resolved component versions; its hash is
checked against the manifest before and after firmware builds. Update the lock
and manifest together only when deliberately changing dependencies.

ESP-IDF 6.1 is a build candidate with [hardware qualification pending](ESP-IDF-6.1-QUALIFICATION.md).
Build success does not establish physical BLE, USB, power, or wake behavior.

Setup never updates an existing installation automatically; it validates HEAD, tracked or
untracked modifications, and submodule state before export or build.

```bash
scripts/setup-esp-idf-local.sh
scripts/setup-esp-idf-local.sh --check
eval "$(scripts/setup-esp-idf-local.sh --export)"
```

A fresh checkout may use the setup script, then the verifier. If the SDK is
absent, host-only and fast checks remain usable while required firmware stages
fail explicitly.

## KiCad and host prerequisites

The strict hardware path requires `kicad-cli` 10.x (the tested host is 10.0.6)
and uses `--severity-all --format json --exit-code-violations`; it does not parse English
console summaries or modify source boards. Reports must exist and contain the
required ERC `sheets[*].violations` or DRC `violations`, `unconnected_items`,
and `schematic_parity` arrays. Host prerequisites are CMake 3.16 or newer,
a C11 compiler with ASan/UBSan support (Clang or GCC), Ruby with YAML and CSV,
Python 3.10 or newer, Node.js 18 or newer, Git, and Bash. Exact host patch
versions are not pinned. OpenSCAD is recorded when available for CAD provenance;
these checks do not render mechanical models.

## Profile and all-target builds

The active optical profile is selected automatically. To request the profile
explicitly with a ring build:

```bash
scripts/verify-firmware-local.sh --firmware-only --ring-profile r30-oled-none-none ring
```

No flashing, hardware-in-the-loop, SDK migration, or CAD mutation is part of
this verifier. Those activities require separate review and evidence.

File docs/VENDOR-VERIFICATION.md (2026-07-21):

# Multi-Source Vendor Verification

Last verified: 2026-03-26

This document checks whether each BOM line item across all four PowerFinger
variants is available from at least two independent distributors, whether listed
alternatives are actually viable, and flags single-source risks.

---

## Verification Summary

| Status | Count |
|---|---|
| Multi-source verified | 11 |
| Single-source (alt available) | 5 |
| Single-source (no alt) | 2 |
| Commodity (multi-source by nature) | 10 |

**Critical findings:**

1. The ESP32-C3-MINI-1-N4 is marked NRND (Not Recommended for New Designs) by
   Espressif. The successor is ESP32-C3-MINI-1-N4X (chip rev v1.1, same pinout).
   Stock remains plentiful but this should be tracked.
2. The PAW3204DB-TJ3L is not stocked by any major Western distributor (DigiKey,
   Mouser, Farnell). It is only available through AliExpress, small Chinese
   brokers, and Octopart-listed specialty houses. The listed alt YS8205 is not a
   real standalone component -- it is an integrated USB mouse controller IC
   harvested from disposable mice and is not a viable alternative.
3. The Snaptron SQ-05400N is sold direct from Snaptron and through DigiKey
   Marketplace, but not through standard DigiKey/Mouser catalog stock. Minimum
   order quantities may apply.
4. The MCP73831 is NOT pin-compatible with the TP4054 without careful PCB
   layout review. The TP4054 is SOT-23-5; the MCP73831 is available in SOT-23-5
   but with a different pin assignment. The BOM's "Alt: MCP73831" note needs a
   caveat.
5. The TP4056 is NOT package-compatible with the TP4054. The TP4056 uses SOP-8
   (8-pin), not SOT-23-5. The BOM already notes it is "larger, through-hole
   friendly for prototype" but calling it an "Alt" is misleading for production.
6. The AH3503 (listed alt for DRV5053) comes in TO-92 by default, not SOT-23.
   SOT-23 variants exist but are harder to source. Pin ordering differs. This is
   not a drop-in alternative without footprint changes.

### Factory Quote Readiness

The component sourcing data above is not a manufacturer quote and does not
prove build readiness. The current Shenzhen / Seeed packet is
[`docs/sensors-converge-2026/SHENZHEN-SEEED-QUOTE-PACKET.md`](sensors-converge-2026/SHENZHEN-SEEED-QUOTE-PACKET.md).

Use that packet with these constraints:

- `USB-HUB` is the send-now quote path: the packet records
  all-severity ERC=0, PCB DRC=0, unconnected=0, and schematic parity=0.
- `R30-OLED-NONE-NONE` is an explicit DFM/pre-fab review annex, not a
  fabrication or assembly quote request. Its quote-facing KiCad status and
  generated-output review are owned by
  [`hardware/ring/R30-OLED-NONE-NONE/kicad/CURRENT-VIOLATIONS.md`](../hardware/ring/R30-OLED-NONE-NONE/kicad/CURRENT-VIOLATIONS.md)
  and
  [`hardware/ring/R30-OLED-NONE-NONE/kicad/FABRICATION-OUTPUTS.md`](../hardware/ring/R30-OLED-NONE-NONE/kicad/FABRICATION-OUTPUTS.md).
  Ask for DFM/pre-fab review and costability feedback until board-house output
  constraints and physical fit/stackup evidence are closed.
- Do not turn distributor availability into vendor commitments. MOQ, lead time,
  yield, defects, realized COGS, payment terms, and license/source-return
  behavior belong in [`docs/REFERENCE-MANUFACTURERS.md`](REFERENCE-MANUFACTURERS.md)
  only after a real quote, run, or direct verification.
- Incoming factory quote files, proposed substitutions, DFM asks, and returned
  source artifacts should first be captured once under
  [`docs/sensors-converge-2026/factory-replies/`](sensors-converge-2026/factory-replies/).
  Factory sourcing claims remain quote-only here until independently checked
  against distributor or received-sample evidence.

---

## Detailed Results

### Active Components (ICs and Modules)

---

#### ESP32-C3-MINI-1-N4
*Used in: all ring variants, wand*

| Distributor | Status | Notes |
|---|---|---|
| DigiKey | In stock | Ships same day. PN: 13877574 |
| LCSC | In stock | C2838502. ~18k units. $2.01 |
| Mouser | Listed | Espressif is a Mouser-stocked brand; specific stock not confirmed via search |
| Farnell | Not checked | Espressif modules generally available |

- **Alternative (ESP32-C3-MINI-1-H4):** In stock at DigiKey. Same pinout, same
  module family. Only difference is extended temperature range (-40 to 105C vs
  85C). True drop-in replacement.
- **Alternative (ESP32-C3-MINI-1-N4X):** Recommended successor (chip rev v1.1).
  Same pinout. Should be the target for new PCB revisions.
- **NRND warning:** The -N4 (chip rev v0.4) is marked Not Recommended for New
  Designs. Stock is still plentiful but the project should migrate to -N4X.
- **Verdict: Multi-source verified (with NRND caveat)**

---

#### ESP32-S3-MINI-1-N8
*Used in: USB hub dongle*

| Distributor | Status | Notes |
|---|---|---|
| DigiKey | In stock | Ships same day. PN: 15295890 |
| Mouser | In stock | Listed on Mouser product page |
| LCSC | In stock | C2913206. ~6.4k units. ~$3.26 |

- **Alternative (ESP32-S3-MINI-1-N4R2):** In stock at LCSC (C3013941, ~$3.42)
  and DigiKey. Same pinout. 4MB flash + 2MB PSRAM vs 8MB flash. True drop-in
  with firmware flash size adjustment.
- **Verdict: Multi-source verified**

---

#### PAW3204DB-TJ3L (optical mouse sensor)
*Used in: standard optical ring*

| Distributor | Status | Notes |
|---|---|---|
| DigiKey | Not stocked | Not in DigiKey catalog |
| Mouser | Not stocked | Not in Mouser catalog |
| LCSC | Not confirmed | No listing found in searches |
| AliExpress | Available | Typically $0.50-1.50, sold as sensor+lens kits |
| Octopart | 3 distributors listed | Specialty/broker distributors only |
| Jotrin, Ariat-Tech | Listed | Small Chinese component brokers |

- **Alternative (ADNS-2080):** In stock at DigiKey (ships same day). Broadcom
  part. Same SPI interface, 8-DIP optical module. Functionally equivalent for
  low-power mouse applications. This is the strongest Western-sourced alt.
- **Alternative (YS8205):** NOT a viable alternative. The YS8205 is an
  integrated USB mouse controller with built-in sensor -- it has its own USB
  stack and is not an SPI peripheral sensor. It is harvested from disposable
  mice, not sold as a component. BOM should remove this as an alt.
- **Supply chain risk:** This is a PixArt part distributed through PixArt's
  authorized channel (EPS Global) and Chinese brokers. Not available through
  any tier-1 Western distributor for small quantities. The AliExpress
  sensor+lens kit channel is the realistic prototype source.
- **Verdict: Single-source risk (AliExpress). ADNS-2080 is a viable Western-sourced alt.**

---

#### DRV5053VAQDBZR (linear Hall effect sensor)
*Used in: ball ring (x4), wand (x4)*

| Distributor | Status | Notes |
|---|---|---|
| DigiKey | In stock | Ships same day. PN: 5015738 |
| LCSC | In stock | C962159. ~$0.14 |
| Mouser | Expected available | TI parts are universally stocked at Mouser |

- **Alternative (AH3503):** Available, but with caveats. The AH3503 from
  Nanjing AH Electronics comes in TO-92 package by default, not SOT-23. SOT-23
  variants (SOT-23-3L) exist per the datasheet but are harder to source. Pin
  ordering (VCC/GND/OUT) differs from DRV5053 (VCC/OUT/GND) -- this is NOT a
  drop-in replacement without PCB changes. Also, the AH3503 minimum supply
  voltage is 3.5V (some datasheets say 4.5V) vs DRV5053's 2.5V, which may
  cause issues at low battery. The AH3503 also draws 6-14mA vs DRV5053's 3mA,
  significantly worse for battery life with 4 sensors.
- **Verdict: Multi-source verified. AH3503 alt is NOT pin-compatible -- BOM
  should flag this.**

---

#### TP4054 (LiPo charge controller)
*Used in: all ring variants, wand*

| Distributor | Status | Notes |
|---|---|---|
| DigiKey | In stock | UMW and EVVO brands. Ships same day |
| LCSC | In stock | C382138 (TPOWER). C32574. ~$0.03 |
| Mouser | Not confirmed | Not a Mouser-typical brand |

- **Alternative (TP4056):** NOT pin-compatible. The TP4056 is SOP-8 (8-pin)
  vs TP4054's SOT-23-5. Different package, different footprint. The BOM
  correctly notes "larger, through-hole friendly for prototype" but listing it
  as "Alt" is misleading for production boards. It is a functional equivalent
  only if the PCB has a separate TP4056 footprint.
- **Alternative (MCP73831):** Functionally similar. Available in SOT-23-5 from
  Microchip (DigiKey, Mouser, widely stocked). However, pinout is NOT
  identical to TP4054 -- pin assignment differs. The MCP73831 datasheet shows
  a different pin 1 function. This requires PCB layout verification before
  claiming drop-in compatibility.
- **Alternative (LTC4054):** The original design that TP4054 clones. Same
  SOT-23-5, closest to pin-compatible. Available at DigiKey from Analog
  Devices. This is the best true alt if TP4054 becomes unavailable.
- **Verdict: Multi-source verified (DigiKey + LCSC). Alt compatibility
  notes need correction in BOM.**

---

#### RT9080-33GJ5 (3.3V ultra-low-Iq LDO)
*Used in: all ring variants, wand*

| Distributor | Status | Notes |
|---|---|---|
| DigiKey | In stock | Ships same day. PN: 6161634 |
| LCSC | In stock | C882092. ~59k units |
| Mouser | Not confirmed in search | Richtek parts typically available |
| Newark | In stock | PN: 06AC2505 |

- **Alternative (XC6220B331MR-G):** In stock at DigiKey, Mouser, and LCSC
  (C86534, ~21k units). SOT-25-5 package (same as TSOT-23-5 for practical
  purposes). However, the XC6220 has 8uA quiescent current vs RT9080's 0.5uA
  -- a 16x difference that matters for deep sleep power budget. It is a
  functional alt but a significant performance downgrade for this application.
  The BOM correctly notes "NOT AP2112K" but should also note the Iq tradeoff
  for XC6220.
- **Verdict: Multi-source verified**

---

### Switches

---

#### Snaptron SQ-05400N (metal snap dome)
*Used in: all ring variants, wand (optional)*

| Distributor | Status | Notes |
|---|---|---|
| DigiKey Marketplace | Possibly available | Snaptron is a DigiKey supplier partner, but the specific SQ-05400N was not found in catalog search |
| Mouser | Not found | Not in standard catalog |
| LCSC | Not found | Not stocked |
| Snaptron direct | Available | Order direct from snaptron.com |

- **Alternatives:** The BOM correctly notes "any 4-6mm metal dome, 150-250gf
  actuation" from Murata or C&K. These are commodity metal dome switches
  available from multiple sources. DigiKey stocks various Snaptron dome
  models (GX and F series) through their marketplace.
- **Risk assessment:** Low. Metal snap domes are commodity items made to
  standard dimensions. The specific Snaptron part number matters less than the
  dimensional and force specs. Any 5mm round dome with ~200gf actuation will
  work.
- **Verdict: Single-source for specific PN (Snaptron direct), but commodity
  category with many equivalent parts.**

---

#### Kailh GM8.0 (micro switch, wand barrel button)
*Used in: wand*

| Distributor | Status | Notes |
|---|---|---|
| DigiKey | Not found | Not in DigiKey catalog |
| Mouser | Not found | Not in Mouser catalog |
| LCSC | Not confirmed | Not found in search results |
| AliExpress | Available | ~$0.20-0.50 per switch |
| Amazon | Available | 4-packs, various sellers |
| kailhswitch.net | Available | Official Kailh store |

- **Alternative (Omron D2FC-F-7N):** In stock at DigiKey (multiple variants:
  20M, 60M, 100M cycle life). In stock at LCSC (~$0.29). Widely available
  from all major distributors. Same 3-pin mouse micro switch footprint. This
  is the industry standard mouse switch and an excellent fallback.
- **Verdict: Single-source for Kailh GM8.0 (AliExpress/direct). Omron D2FC
  alt is fully multi-source and pin-compatible.**

---

### Passive Components and Commodity Items

These are standard commodity parts available from any electronics distributor.
Verification is provided at category level rather than per-part.

---

#### 100nF 0402 MLCC Capacitor
*Used in: all variants (x2 each)*

- Available from every distributor. Millions of units in stock globally.
  Multiple manufacturers (Samsung, Murata, Yageo, TDK).
- **Verdict: Commodity, multi-source by nature**

---

#### 10uF 0402/0603 MLCC Capacitor
*Used in: all variants*

- Standard bulk/bypass cap. Available everywhere.
- **Verdict: Commodity, multi-source by nature**

---

#### 10k ohm 0402 Resistor
*Used in: all variants (charge current set)*

- Available from every distributor.
- **Verdict: Commodity, multi-source by nature**

---

#### USB-C Connector (2.0 receptacle, SMD)
*Used in: all ring variants, wand*

- Generic USB-C 2.0 receptacles are commodity items at LCSC (hundreds of
  listings). Also available at DigiKey and Mouser from brands like GCT, Amphenol,
  Wurth, Molex.
- **Verdict: Commodity, multi-source by nature**

---

#### USB-A Male Connector
*Used in: USB hub dongle*

- Standard through-hole or SMD USB-A plug. Commodity at all distributors.
- **Verdict: Commodity, multi-source by nature**

---

#### IR/Red LED (0603)
*Used in: standard optical ring*

- Generic indicator LED. Available everywhere. Often included with sensor kits.
- **Verdict: Commodity, multi-source by nature**

---

#### Status LED (0402, green) + 1k ohm resistor
*Used in: USB hub dongle*

- Standard parts at any distributor.
- **Verdict: Commodity, multi-source by nature**

---

#### Tactile Switch (6x6mm, boot/reset button)
*Used in: USB hub dongle*

- Standard 6x6mm tactile switch. Commodity at all distributors.
- **Verdict: Commodity, multi-source by nature**

---

#### 2.4GHz Chip Antenna
*Used in: noted in optical ring BOM but ESP32-C3-MINI-1 has onboard antenna*

- Only needed if using U.FL module variant. Standard 2.4GHz chip antennas
  available from Johanson, Fractus, Abracon at all major distributors.
- **Verdict: Commodity (and likely not needed)**

---

### Mechanical and Custom Components

These components are inherently outside the traditional electronics distributor
ecosystem. They are verified against their specific sourcing channels.

---

#### LiPo Battery (80-100mAh / 100-150mAh pouch cell)
*Used in: all ring variants (80-100mAh), wand (100-150mAh)*

- Small LiPo pouch cells are commodity items on AliExpress. Multiple Chinese
  cell manufacturers. The size constraint (20x15x4mm for ring, 40x10x5mm for
  wand) limits options but cells in this range are widely available from brands
  like DTP, Shenzhen Data Power, and others.
- Not available from DigiKey/Mouser at these sizes (they stock Renata, Varta
  coin cells which are different chemistry/form factor).
- **Verdict: Commodity within AliExpress ecosystem. Not available from
  Western distributors at required sizes.**

---

#### 5mm Steel Ball
*Used in: ball ring, wand*

- Chrome steel or stainless steel bearing balls. Available from McMaster-Carr,
  AliExpress, Amazon, and any bearing supplier.
- **Verdict: Commodity, multi-source by nature**

---

#### 1x1mm N52 Neodymium Magnets
*Used in: ball ring (x4), wand (x4)*

- Micro neodymium magnets in this size are available from AliExpress, Amazon
  (various magnet vendors), and specialty magnet suppliers (K&J Magnetics,
  first4magnets). Not a standard electronics distributor item.
- **Verdict: Commodity within magnet/hobby supplier ecosystem**

---

#### Roller Spindles
*Used in: ball ring (x4), wand (x4)*

- Custom or modified parts. Will likely need to be fabricated (CNC lathe or
  sourced as modified dowel pins). This is the most custom mechanical component
  in the BOM.
- **Verdict: Custom fabrication required. No off-the-shelf source.**

---

#### UHMWPE Glide Pads
*Used in: standard optical ring (x4)*

- Punched from UHMWPE sheet stock. McMaster-Carr stocks UHMWPE sheet in various
  thicknesses. Also available from AliExpress and plastics suppliers.
- **Verdict: Commodity raw material, custom punching required**

---

#### PCBs (flex/rigid-flex/rigid)
*Used in: all variants*

- JLCPCB, PCBWay, OSH Park, and dozens of other PCB fabricators. Standard
  service.
- **Verdict: Commodity service, multi-source by nature**

---

#### 3D-Printed Shells, Sockets, Tips, Caps
*Used in: all variants*

- Any FDM/SLS printer or service bureau (JLCPCB 3D printing, Shapeways,
  Craftcloud, local makerspaces).
- **Verdict: Commodity service, multi-source by nature**

---

#### Aluminum/Stainless Tube (wand body)
*Used in: wand*

- 8mm OD tubing from McMaster-Carr, AliExpress, Amazon, or any metals supplier.
  Cut to length.
- **Verdict: Commodity, multi-source by nature**

---

## BOM Correction Recommendations

Based on this verification, the following BOM changes are recommended:

### Corrections to Make

1. **Remove YS8205 as PAW3204 alt.** The YS8205 is not an SPI mouse sensor --
   it is an integrated USB mouse controller. It cannot substitute for the
   PAW3204DB in this design. Replace with a note that ADNS-2080 (DigiKey) is
   the verified Western-source alternative.

2. **Flag AH3503 as NOT pin-compatible with DRV5053.** Different pin ordering
   (VCC/GND/OUT vs VCC/OUT/GND), default TO-92 package (not SOT-23), higher
   minimum voltage (3.5V+), and 2-5x higher current draw. Requires PCB changes
   to use. Change from "Alt" to "Functional equivalent (different footprint and
   pinout)."

3. **Clarify TP4056 is NOT a drop-in alt for TP4054.** Different package
   (SOP-8 vs SOT-23-5). Add note: "Requires separate footprint on PCB." Add
   LTC4054 (Analog Devices) as the true pin-compatible alt.

4. **Add pinout caveat to MCP73831 alt.** The MCP73831 in SOT-23-5 has a
   different pin assignment than the TP4054. Note: "Requires PCB layout
   verification. Not a blind drop-in."

5. **Add NRND note to ESP32-C3-MINI-1-N4.** Note that Espressif recommends
   migrating to ESP32-C3-MINI-1-N4X (chip rev v1.1, same pinout, more flash
   space). Current stock is plentiful but long-term availability is uncertain.

6. **Add XC6220 Iq caveat.** The XC6220B331MR has 8uA Iq vs RT9080's 0.5uA.
   Note the 16x quiescent current penalty in the alt column, since deep sleep
   power budget is a first-order design concern.

### Additions to Make

7. **Add ADNS-2080 to optical ring BOM** as the verified Western-source
   fallback class. Treat it as a board-profile change until its footprint,
   optics, aperture, and firmware behavior are evaluated against the active
   ring packet.

8. **Add LTC4054ES5-4.2 to all BOMs** as the true pin-compatible charger IC
   alternative (Analog Devices, DigiKey PN: 960438).

9. **Add ESP32-C3-MINI-1-N4X to all C3 BOMs** as the recommended successor
   module.

---

## Risk Matrix by Variant

### R30-OLED-NONE-NONE (Standard Optical Ring, ~$9)

| Component | Risk | Mitigation |
|---|---|---|
| PAW3204DB-TJ3L | HIGH | AliExpress/sensor-kit lane only. Evaluate ADNS-2080 as the Western-source fallback before relying on it for the active board |
| Snaptron SQ-05400N | LOW | Any 5mm dome works. Commodity category |
| LiPo pouch cell | LOW | Commodity on AliExpress. Multiple vendors |
| All other parts | NONE | Multi-source verified |

### R30-BALL-NONE-NONE (Ball+Hall Ring, ~$11)

| Component | Risk | Mitigation |
|---|---|---|
| Roller spindles | MEDIUM | Custom fab required. No off-the-shelf source |
| Snaptron SQ-05400N | LOW | Any 5mm dome works |
| LiPo pouch cell | LOW | Commodity on AliExpress |
| All other parts | NONE | Multi-source verified |

### WSTD-BALL-NONE-NONE (Wand, ~$14)

| Component | Risk | Mitigation |
|---|---|---|
| Kailh GM8.0 | LOW | AliExpress only, but Omron D2FC is multi-source drop-in |
| Roller spindles | MEDIUM | Custom fab required |
| Aluminum tube | NONE | McMaster + many sources |
| All other parts | NONE | Multi-source verified |

### USB-HUB (Hub Dongle, ~$5-6)

| Component | Risk | Mitigation |
|---|---|---|
| (none elevated) | NONE | All parts multi-source or commodity |

---

## Methodology and Limitations

This verification was conducted via web search of distributor websites on
2026-03-26. The following limitations apply:

- **Stock quantities are point-in-time snapshots.** Distributor inventory
  changes daily. "In stock" means the part was listed as available on the
  date checked, not that it will be available at time of order.
- **Mouser verification was indirect** for several parts. Mouser product pages
  were confirmed to exist but exact stock counts were not always returned by
  search. Mouser carries Espressif, TI, Richtek, Microchip, and Torex as
  stocked brands, so availability is expected but not individually confirmed
  for every MPN.
- **AliExpress "availability" is inherently fuzzy.** Multiple sellers list
  the same parts; some are genuine, some are relabeled. For prototype
  quantities this is acceptable. For production, authenticated distributor
  channels are preferred.
- **Broker/specialty distributor stock** (Jotrin, Ariat-Tech, OMO Electronic)
  was noted but not independently verified. These sources often carry stock
  but may have higher prices or longer lead times.
- **Pin compatibility claims** were checked against datasheets where possible
  but full electrical validation requires physical testing.

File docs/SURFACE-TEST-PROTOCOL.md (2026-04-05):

# Surface Compatibility Test Protocol

A complete, reproducible test protocol for evaluating PowerFinger tracking
performance across all target surfaces. Designed to be executable on day 1 of
hardware arrival by someone who has never tested a mouse sensor before.

References:
- Prototype spec: [PROTOTYPE-SPEC.md](PROTOTYPE-SPEC.md)
- Design matrix: [COMBINATORICS.md](COMBINATORICS.md)
- Glide system: [GLIDE-SYSTEM.md](GLIDE-SYSTEM.md)
- Power budget: [POWER-BUDGET.md](POWER-BUDGET.md)

---

## 1. Equipment List

### Required

| Item | Purpose | Approximate Cost | Source |
|---|---|---|---|
| Steel ruler, 300mm | Linear guide for controlled-speed drag | $5 | Hardware store |
| Digital calipers (150mm, 0.01mm resolution) | Measure physical displacement | $15 | Amazon, hardware store |
| Smartphone with 240fps+ slow-motion video | Latency measurement | Already owned | iPhone 12+ or Galaxy S21+ |
| Tripod or phone clamp | Steady camera for latency and jitter recording | $10 | Amazon |
| Kitchen scale (0.1g resolution) | Calibrate finger pressure weights | $10 | Amazon |
| Small weight set: 50g, 100g, 200g | Simulate controlled finger pressure (0.5N, 1N, 2N) | $8 | Fishing weights or lab weights |
| USB mouse jiggle detection software | Log raw HID reports with timestamps | Free | `evtest` (Linux), MouseTester (Windows) |
| Laptop/desktop with BLE and screen recording | Host for BLE HID connection and data logging | Already owned | Any OS |
| Masking tape | Mark start/end positions on surfaces | $3 | Hardware store |
| Fine-tip marker | Mark reference lines on tape (not on test surfaces) | $2 | Office supply |
| Rubber band or silicone strap (optional) | Secure weight to ring during pressure-controlled tests | $1 | Office supply |

### Test Surfaces (acquire before hardware arrives)

| # | Surface | Specimen | Where to Get |
|---|---|---|---|
| S01 | Wood desk (unfinished) | 300x300mm plywood or hardwood scrap | Hardware store |
| S02 | Wood desk (lacquered) | 300x300mm varnished wood panel or actual desk surface | Desk or hardware store |
| S03 | Glass | 300x300mm clear glass pane, 3-4mm thick | Hardware store, picture frame glass |
| S04 | Fabric (cotton) | 300x300mm cotton cloth, flat weave (e.g., plain T-shirt material) | Fabric store or old shirt |
| S05 | Paper (printer paper) | Standard A4/Letter, taped flat to a hard surface | Office supply |
| S06 | Glossy magazine | Magazine cover or glossy photo paper, taped flat | Newsstand |
| S07 | Matte plastic | 300x300mm ABS or HDPE sheet, matte finish | Plastics supplier, cutting board |
| S08 | Wheelchair tray (vinyl-coated) | Vinyl-coated plywood or actual wheelchair tray surface sample | Medical supply, or vinyl wrap on plywood |
| S09 | Wheelchair tray (powder-coated metal) | Powder-coated aluminum or steel panel | Metal supplier, or actual tray sample |
| S10 | Hospital bed rail (chrome) | Chrome-plated steel tube or flat chrome sample | Plumbing supply, or actual rail segment |
| S11 | Hospital bed rail (painted steel) | Painted steel tube or flat painted steel sample | Hardware store (painted shelf bracket) |
| S12 | Skin (forearm) | Tester's own forearm, positioned flat on table | N/A |
| S13 | Skin (thigh) | Tester's own thigh, seated position | N/A |
| S14 | Clothing (cotton, worn) | Cotton pants or sleeve, on the body in normal position | N/A |
| S15 | Clothing (denim, worn) | Jeans, on the body in normal position | N/A |
| S16 | Clothing (fleece, worn) | Fleece jacket sleeve or lap blanket, on the body | N/A |

**Accessibility note:** Surfaces S08-S16 are the actual use environment for
target users. A ring that scores perfectly on S01-S07 but fails on S08-S16 has
failed its purpose. Prioritize these surfaces in reporting.

---

## 2. Software Setup

### HID Report Logger

The logger must capture raw BLE HID mouse reports (X delta, Y delta, button
state) with host-side timestamps at report-level granularity.

**Linux (recommended):**
```bash
# Find the ring's event device after pairing
sudo evtest /dev/input/eventN
# Or for structured logging:
sudo evemu-record /dev/input/eventN > test_log.txt
```

**Windows:**
- MouseTester by microe (GitHub). Run it, pair the ring via BLE, start recording.
  Export as CSV.

**macOS:**
- IOHIDEventSystemClient sample code, or use Karabiner-EventViewer for quick
  visual verification then switch to a Linux machine for structured logging.

### Screen Recording for Latency

Use the smartphone at 240fps (or higher). Frame the screen and the ring in the
same shot. The phone must see both the physical ring movement and the on-screen
cursor movement simultaneously.

---

## 3. Test Fixture Setup

### 3.1 Linear Guide (Controlled-Speed Drag)

```
TOP VIEW — Linear drag fixture

  ┌─────────── 300mm ruler (steel) ──────────┐
  │                                            │
  ══════════════════════════════════════════════
  ↑ START mark                    STOP mark ↑
  (masking tape)                 (masking tape)
  │←────────── 100mm ───────────→│
```

1. Place a strip of masking tape at the 0mm and 100mm marks on the ruler.
2. Draw a fine line across each tape strip as a visual start/stop cue.
3. Tape the ruler firmly to the test surface so it does not slide.
4. The ring slides along the ruler edge. The ruler acts as a guide rail, not a
   drag surface — the ring's glide pads (or ball) contact the test surface
   beneath it, and the ruler provides lateral constraint so the path is straight.

**For ball-sensor variants (no glide pads):** The ball contacts the test surface
directly. The ruler edge guides the ring shell.

**For skin/clothing tests (S12-S16):** The ruler cannot be taped to skin. Instead,
draw two dots 100mm apart on masking tape applied to the skin/clothing. Move the
ring between the dots freehand, using the tape marks as start/stop references.
Accept that these tests will have higher variance; run 5 trials instead of 3.

### 3.2 Controlled Pressure

Normal finger pressure during ring use is 0.5-2N (50-200g force). The ring's own
weight (~8-15g) is far below this range. During testing, simulate finger pressure
using dead weights:

| Pressure Level | Weight on Ring | Force | Represents |
|---|---|---|---|
| Light | 50g | ~0.5N | Very light touch, minimal contact |
| Normal | 100g | ~1.0N | Typical relaxed finger resting on surface |
| Firm | 200g | ~2.0N | Deliberate press, e.g., during a drag operation |

**How to apply weight:** Place the weight directly on top of the ring body,
centered over the sensor. For small weights, use a coin stack or fishing weights
in a small bag. Secure with a rubber band or silicone strap if the weight tends
to slide off during drag tests. The weight must not block the sensor aperture or
interfere with the glide pads / ball.

**For skin/clothing tests:** Use finger pressure only (no dead weights on the
body). Record subjective pressure as "light / normal / firm" based on the
tester's self-assessment. These tests assess whether the sensor tracks on the
surface at all, not precision at controlled pressure.

### 3.3 Controlled Angle

All ring tests default to 30 degrees (matching the R-30 shell design). The ring
shell geometry enforces the angle — when the glide pads sit flat on the surface,
the sensor is at 30 degrees. No external angle fixture is needed for ring tests.

For wand tests, test at three angles from horizontal: 30, 50, and 70 degrees.
Use a protractor or angle block to verify. For ball+Hall PowerPen bring-up, run
the tracking-accuracy drag both horizontally and vertically at each angle and
record the per-axis sensitivity ratio
`max(horizontal counts_total, vertical counts_total) / min(...)` in
`POWERPEN-SPEC.md`. Ratios above 3:1 flag a follow-up for dynamic gain
compensation; they are not an automatic test failure.

---

## 4. Test Procedures

Run all five tests on every surface. For each surface, start fresh: re-pair BLE
if needed, verify cursor is responding, then proceed through tests in order.

### 4.1 Tracking Accuracy (Linearity)

**What this measures:** When the ring moves 100mm on the surface, how far does
the cursor actually move? And is the relationship linear (consistent across the
stroke)?

**Procedure:**

1. Open a drawing program (MS Paint, GIMP, or any canvas app). Set brush to 1px.
2. Start the HID logger.
3. Position the ring at the START mark.
4. Draw a straight horizontal line on screen by dragging the ring from START to
   STOP (100mm) along the ruler guide at approximately 50mm/s (~2 seconds for
   the full stroke). Do not rush.
5. Stop the HID logger.
6. Measure the on-screen line length in pixels. Record as `px_total`.
7. From the HID log, sum all X-delta values during the stroke. This is the raw
   sensor output in counts. Record as `counts_total`.
8. Divide the stroke into 5 equal segments (20mm each) by examining the HID log
   timestamps. For each segment, compute counts for that segment. Record as
   `counts_seg[1..5]`.
9. Repeat 3 times (5 times for skin/clothing surfaces). Record all trials.

**Derived metrics:**

| Metric | Formula | Units |
|---|---|---|
| Resolution | `counts_total / 100` | counts/mm |
| On-screen ratio | `px_total / 100` | px/mm |
| Linearity error | `max(counts_seg) - min(counts_seg)) / mean(counts_seg) * 100` | % deviation |

**Notes:**
- The px/mm ratio depends on the host OS sensitivity setting. Record the OS
  pointer speed setting and keep it constant across all tests.
- Counts/mm is the sensor-intrinsic metric and is more meaningful for
  cross-surface comparison. Use it as the primary metric.
- For ball+Hall PowerPen bring-up, repeat the stroke in both X and Y directions
  at each of the three test angles and compute the per-axis sensitivity ratio
  from the two `counts_total` values. Record that ratio alongside the surface
  results in `POWERPEN-SPEC.md`.

### 4.2 Jitter at Rest

**What this measures:** When the ring is sitting still on the surface, does the
cursor drift? This matters for accessibility users who may leave the ring resting
on a surface while doing other tasks.

**Procedure:**

1. Place the ring on the test surface with 100g weight (normal pressure).
2. Start the HID logger.
3. Do not touch the ring or the surface. Do not walk near the table (vibration).
4. Wait 60 seconds.
5. Stop the HID logger.
6. From the log, extract all X and Y deltas reported during the 60 seconds.

**Derived metrics:**

| Metric | Formula | Units |
|---|---|---|
| Total displacement | `sqrt(sum(dx)^2 + sum(dy)^2)` | counts |
| RMS jitter | `sqrt(mean(dx^2 + dy^2))` per report | counts/report |
| Max single-report jump | `max(sqrt(dx_i^2 + dy_i^2))` | counts |
| Cumulative pixel drift | Measure cursor displacement on screen after 60s | px |

**Notes:**
- For skin/clothing, the tester must remain as still as possible. Breathing and
  micro-movements will produce some motion. Record whether the tester was seated
  (thigh tests) or had arm resting on table (forearm tests). Accept that
  biological surfaces have inherently higher jitter.
- If the sensor enters a low-power sleep mode during the 60 seconds (expected
  for PAW3204 after ~256ms of no motion), note the transition point.

### 4.3 Dropout Rate

**What this measures:** During a continuous drag, how often does the sensor lose
tracking and report zero movement? Dropouts cause cursor stutter and are
especially disorienting for users with motor control challenges.

**Procedure:**

1. Start the HID logger.
2. Drag the ring along the ruler guide at a steady ~50mm/s for 100mm.
3. Without lifting, drag back to START at the same speed.
4. Stop the HID logger.
5. From the log, count total HID reports during the drag (N_total) and reports
   where both dx=0 and dy=0 (N_zero).
6. Repeat 3 times (5 times for skin/clothing). Record all trials.

**Derived metrics:**

| Metric | Formula | Units |
|---|---|---|
| Dropout rate | `N_zero / N_total * 100` | % |
| Max consecutive dropouts | Longest run of zero-delta reports | reports |
| Dropout duration | `Max consecutive dropouts * report_interval_ms` | ms |

**Notes:**
- A report with dx=0 and dy=0 during movement is a dropout. But at very low
  speeds, some zero reports are expected because sub-count movements round to
  zero. To distinguish: zero reports at 50mm/s with a sensor rated for >400
  counts/inch are true dropouts.
- On glass (S03), expect high dropout rates from optical sensors. This is a
  known limitation. The purpose of testing glass is to quantify how bad it is,
  not to expect it to pass.

### 4.4 Latency (End-to-End)

**What this measures:** The total delay from when the ring physically moves to
when the cursor visibly moves on screen. This includes sensor capture time, MCU
processing, BLE transmission, host processing, and display pipeline.

**Procedure:**

1. Set up the smartphone in slow-motion mode (240fps minimum). Mount on tripod.
2. Frame the shot so both the ring on the surface AND a portion of the monitor
   showing the cursor are visible simultaneously.
3. Place the ring at the START mark with 100g weight.
4. Start video recording.
5. Make a quick, sharp movement of the ring (~30mm in ~0.2 seconds). The
   movement must be abrupt enough that the exact start frame is unambiguous in
   slow-motion footage.
6. Stop video recording.
7. Review the slow-motion footage frame by frame:
   - **Frame A:** The first frame where the ring visibly begins to move.
   - **Frame B:** The first frame where the cursor visibly begins to move.
   - **Latency = (B - A) / fps** in seconds. Convert to ms.
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

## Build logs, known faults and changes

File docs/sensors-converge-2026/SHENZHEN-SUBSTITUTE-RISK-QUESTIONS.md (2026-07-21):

<!-- SPDX-License-Identifier: CC-BY-SA-4.0 -->
# Shenzhen Substitute Risk And Factory Questions

This sheet is the first factory-exchange companion for the current Shenzhen /
Seeed packet. It is deliberately narrow:

- Quote path: `USB-HUB` PCB fab/assembly quote, connector/enclosure DFM review,
  and serviceability feedback.
- Annex path: `R30-OLED-NONE-NONE` DFM/pre-fab review only.

Do not use this sheet to quote secondary rings, wands, puck variants, OCR
features, cloud features, or companion-app work.

## Factory-Exchange Rule

Every proposed substitution must come back with:

| Required field | Why it matters |
|---|---|
| Exact manufacturer, MPN, package, and supplier link | Prevents "equivalent" parts from hiding a footprint, pinout, or quality change |
| Whether the current footprint is unchanged | Separates quote-safe sourcing from a PCB revision |
| Whether enclosure or fixture geometry changes | Prevents connector, service-hatch, battery, and focal-distance breakage |
| MOQ, quoted unit price, and availability basis | Keeps vendor data out of `REFERENCE-MANUFACTURERS.md` until it is actually verified |
| Serviceability impact | Accessibility depends on repairable hardware, not sealed disposable assemblies |
| Editable source they will return for DFM changes | Keeps CERN-OHL-S 2.0 source disclosure complete |

Safe substitutions are still not vendor commitments. They are only
quote-permissible candidates until a real quote, batch, or direct verification
exists.

## USB-HUB Send-Now Substitute Guidance

| Ref / subsystem | Active part | Safe within current quote | Footprint-breaking or contract-breaking | First factory ask |
|---|---|---|---|---|
| `U1` MCU/radio/USB | `ESP32-S3-MINI-1-N8` | `ESP32-S3-MINI-1-N4R2` only if the same module footprint is preserved and firmware flash/PSRAM assumptions are called out | ESP32-C3, ESP32-S3-WROOM, no-native-USB modules, or any module with different antenna keep-out / pads | Can you source the active `N8` module? If proposing `N4R2`, confirm exact footprint match, flash/PSRAM delta, and whether the firmware build must change. |
| `J1` USB connector | SOFNG `USB-05`, LCSC `C112454`, USB-A male plug | Same manufacturer/drawing, same shell-tab and through-hole geometry | USB-A receptacle, USB-C connector, cable/pigtail, connector with different shell tabs, or any part that invalidates the direct-plug nose / `MH1` / `MH2` clamp path | Can you source the SOFNG `USB-05` and confirm the manufacturer drawing is USB-A male? If not, send the drawing before quoting assembly. |
| `U2` regulator | RT9080-33GJ5, SOT-23-5 | Same RT9080-33GJ5 footprint from another distributor | AP2112K-class high-Iq regulator, DFN, SOT-89, pinout changes, or a regulator that changes required output-cap stability | Can you keep RT9080? If proposing an LDO substitute, state quiescent current, required output capacitor, pinout, and package. |
| `D1` USB ESD | USBLC6-2SC6, SOT-23-6 | USB 2.0-capable USBLC6-2SC6 with same pinout and package from a verified channel | Rail-less two-line shunt without the intended VBUS branch, different pinout, different package, or a part placed away from connector entry | Can you assemble USBLC6-2SC6 at the connector entry? If substituting ESD, provide capacitance, pinout, and whether VBUS protection remains. |
| `R1A` / `R1B` USB series resistors | 22R, 0402 | Commodity 22R 0402; 33R only if the factory explicitly recommends it for ESP32-S3 USB routing and notes the change | Omitting the resistors, moving them to the connector side of ESD, changing package, or choosing values without USB bring-up rationale | Which value do you recommend for this route length, 22R or 33R, and will you keep them near the ESP32-S3 module side? |
| `C2` / `C3` power capacitors | `10uF` 0603 input, `1uF` effective 0603 output | Commodity X5R/X7R 0603 MLCCs with adequate voltage rating and effective capacitance | Silent 0402 downsizing, low-voltage derating that loses effective capacitance, or changing `C3` below RT9080 stability needs | Which exact MLCCs would you place, and what effective capacitance do you expect at operating bias? |
| `C1`, `LED1`, `R2`, passives | Commodity 0402 support parts | Same value/package commodity substitutions | Package changes that crowd service pads, move the LED out of the visible/serviceable location, or hide status indication behind opaque enclosure material | Can you source these as standard commodity parts while preserving service-pad and enclosure visibility constraints? |
| `SW1` recovery control | Service-size tactile or pad-actuated recovery path | Smaller tact or pad-actuated `BOOT_N` path if the service hatch still reaches it | A large 6x6 tact that breaks the board envelope, hidden switch, destructive access, or omitting recovery pads | What switch or pad-actuated service method do you recommend, and can it remain reachable through the service hatch? |
| PCB / enclosure retention | Stepped USB-A dongle with `MH1` / `MH2` clamp load path | DFM tweaks that keep direct-plug topology, antenna keep-out, service hatch, and reversible clamp hardware | Adhesive, potting, heat-shrink-only retention, brass inserts near antenna, cable-only topology, or connector retention that relies on solder joints alone | What connector-retention and shell-clamp risks do you see before physical coupon evidence exists? |

## USB-HUB Accessibility And Serviceability Non-Negotiables

- The hub must remain a local BLE/USB HID bridge with no cloud dependency.
- The USB connector must be replaceable without discarding the enclosure.
- The enclosure must reopen; glue, potting, sealed heat-shrink, and destructive
  service paths fail the active lane.
- `MH1` / `MH2` remain the explicit connector load path unless the packet is
  revised.
- The service hatch must expose `EN`, `BOOT_N`, UART, power, ground, and trace
  access pads without pulling on the USB connector.
- The ESP32-S3 antenna keep-out must stay free of copper, metal enclosure
  features, and nearby clamp hardware.
- Adjacent-port clearance for the stepped USB-A nose and wider body is an
  open evidence item, not an assumption.

## R30 Annex Substitute Guidance

The R30 ring is not a fabrication quote path in this exchange. Ask for DFM,
costability, assembly, serviceability, and sourcing feedback only.

| Ref / subsystem | Active part | Safe for annex discussion | Footprint-breaking or contract-breaking | First factory ask |
|---|---|---|---|---|
| `U1` MCU/radio | `ESP32-C3-MINI-1-N4` | `ESP32-C3-MINI-1-N4X` or `ESP32-C3-MINI-1-H4` with same pinout; prefer `N4X` for new revisions | ESP32-C3 modules with different footprint, antenna, flash contract, or enclosure keep-out | Can you source `N4X` and confirm same footprint as `N4`? |
| `U2` optical sensor | PAW3204DB-TJ3L sensor/lens/emitter kit | Exact PAW3204 kit with matched lens/emitter | ADNS-2080 as a drop-in, YS8205, generic USB mouse ICs, or unverified SPI optical sensors | Can you source PAW3204 as a matched kit? If not, what proof would you need before an ADNS-2080 board profile is evaluated? |
| `LENS1` optical stack | Sensor-specific lens and clip | Lens/clip matched to the exact PAW3204 package | Bare sensor without a known lens/emitter path, mismatched aperture or focal geometry | Can you identify the lens/emitter kit as one sourced assembly, not loose uncertain parts? |
| `BT1` / `J_BAT` battery service | Protected `80-100 mAh` LiPo with replaceable service harness to off-board pads | Protected pouch cell within shell size, integrated PCM, UN 38.3 paperwork, replaceable harness or fixture tail | Harvested cells, direct cell-tab solder, no PCM, no paperwork, or inaccessible battery removal | Can you supply a protected cell and harness path that keeps battery replacement possible without soldering the cell? |
| `U3` charger | TP4054 SOT-23-5 | LTC4054ES5-4.2 if same pinout/footprint is confirmed | MCP73831 without layout change, TP4056 SOP-8, charger with no explicit charge-current review | Can you keep TP4054/LTC4054 pinout? If proposing MCP73831 or TP4056, treat it as a board revision, not a BOM swap. |
| `U4` regulator | RT9080-33GJ5 SOT-23-5 | Same RT9080; XC6220B331MR only as a documented low-power downgrade | AP2112K, different pinout, larger package, or regulator with sleep current that breaks ring battery assumptions | Can you source RT9080? If proposing XC6220, call out the higher Iq and battery-life impact. |
| `D1` USB service ESD | TPD2E2U06DCK-class rail-less dual TVS, SC-70/SOT-323 | Same pinout/package low-capacitance rail-less dual data-line shunt | USBLC6-style VBUS-clamped topology, different pinout, or package changes in the service-edge pocket | Can you source an equivalent rail-less SC-70/SOT-323 data shunt without adding a VBUS branch? |
| `SW1` click element | 5mm 150-250gf snap dome class | Commodity 4-6mm dome in the same force range after actuator review | Hidden, too-stiff, non-replaceable, or package changes that break limited-mobility click ergonomics | Which dome options can you source, and can replacement remain possible through the serviceable shell? |
| Service interfaces | Off-board USB pads and battery service pads | Fixture/pogo/harness improvements that keep same nets and access | Onboard USB-C body, direct soldered cell, or fixture path that blocks shell reopening | Can you manufacture/test the off-board service pad approach, and what fixture geometry would you recommend? |
| Shell / focal-distance system | Raised rim plus UHMWPE glide pads | Material/process suggestions that preserve focal gap and replaceable pads | Sealed shell, glued pads with no service path, rim changes that invalidate focal-distance evidence | Which shell tolerances, pad material, and inspection checks would you require before quoting ring assembly? |

## R30 Accessibility And Serviceability Non-Negotiables

- Battery service must be replaceable through a harness or fixture; direct cell
  soldering is rejected.
- The shell remains reopenable and non-hermetic through the service-lid path.
- The raised rim and glide pads are accessibility hardware because they control
  focal distance and glide effort; do not casually merge them into an
  unserviceable shell feature.
- The optical surface claim stays honest: opaque rigid surfaces only today,
  not glass.
- The ring is parametric for finger circumference; no fixed one-size shell
  assumption should enter a factory response.
- `ADNS-2080` is a future evaluated board profile, not a PAW3204 drop-in.
- `YS8205`-style integrated USB mouse controllers are not substitutes.

## First Factory Exchange Questions

Send these as the first response checklist after the introductory email:

1. For `USB-HUB`, can you quote PCB fabrication and assembly from the current
   source packet while also giving connector/enclosure DFM notes?
2. Which `USB-HUB` BOM lines would you substitute, if any? For each, provide
   manufacturer, MPN, package, supplier link, MOQ, footprint impact, and
   serviceability impact.
3. Can you source and assemble the SOFNG `USB-05` male USB-A direct-plug
   connector, and do you see any shell-tab, solder-joint, or enclosure-clamp
   risk in the current direct-plug topology?
4. What would you change in the `MH1` / `MH2` clamp path, service hatch, or
   enclosure material while keeping the hub reopenable?
5. Can you keep the ESP32-S3 antenna keep-out clear of copper, metal, screws,
   brass inserts, and enclosure features?
6. What test or fixture access do you need for `EN`, `BOOT_N`, UART, power,
   ground, USB D+/D-, and trace access during assembly?
7. Are you willing to return editable KiCad/OpenSCAD or equivalent source for
   any DFM modifications you make, so CERN-OHL-S 2.0 disclosure remains
   complete?
8. If you accept the R30 annex, can you review it only as DFM/pre-fab input and
   clearly avoid quoting ring fabrication until physical fit/stackup evidence is
   closed?
9. For R30, can you source the PAW3204 sensor/lens/emitter kit and protected
   `80-100 mAh` cell with replaceable harness? If not, which exact alternatives
   do you propose, and which ones require a board or shell revision?
10. What information should be added to the packet before your next response:
    fabrication outputs, centroid/BOM format, enclosure STLs, fixture drawings,
    physical coupon observations, or translated notes?

## Verification Notes

- Read against `docs/sensors-converge-2026/SHENZHEN-PAIRING.md`: this sheet
  keeps Shenzhen focused on supply-chain depth, component cost, factory access,
  and Seeed-style first-batch scoping.
- Read against `docs/VENDOR-VERIFICATION.md`: `USB-HUB` has no elevated
  component-sourcing risk today; R30's elevated risk is the PAW3204 kit path,
  with charger/regulator/Hall-style caveats already documented at part level.
- Read against `docs/REFERENCE-MANUFACTURERS.md`: Seeed, JLCPCB, PCBWay, and
  local prototype houses remain placeholders until quote/run data exists.
- Read against `hardware/bom/USB-HUB.csv` and
  `hardware/shared/USB-HUB/kicad/P0-COMPONENT-LOCKS.md`: USB-HUB substitutions
  are centered on `U1`, `J1`, `U2`, `D1`, USB resistors, power capacitors,
  recovery control, and the direct-plug enclosure clamp path.
- Read against `hardware/bom/R30-OLED-NONE-NONE.csv` and
  `hardware/ring/R30-OLED-NONE-NONE/MANIFEST.md`: the annex guidance keeps
  PAW3204, battery service, charger, low-Iq regulation, rail-less USB ESD,
  focal-distance hardware, and service interfaces explicit.
- No new vendor claim, quote, availability claim, yield, realized COGS, or
  endorsement is created by this sheet.

## Recommended Followup

Use [`SHENZHEN-FACTORY-RESPONSE-CAPTURE.md`](SHENZHEN-FACTORY-RESPONSE-CAPTURE.md)
as the factory-return form that mirrors this sheet as fillable tables for
proposed substitutions, DFM requests, source-return posture, quote-vs-verified
status, and explicit BDFL decisions. The form is included in the quote export so
every factory response can be pasted back into the repo without turning
ambiguous email prose into hidden design decisions.

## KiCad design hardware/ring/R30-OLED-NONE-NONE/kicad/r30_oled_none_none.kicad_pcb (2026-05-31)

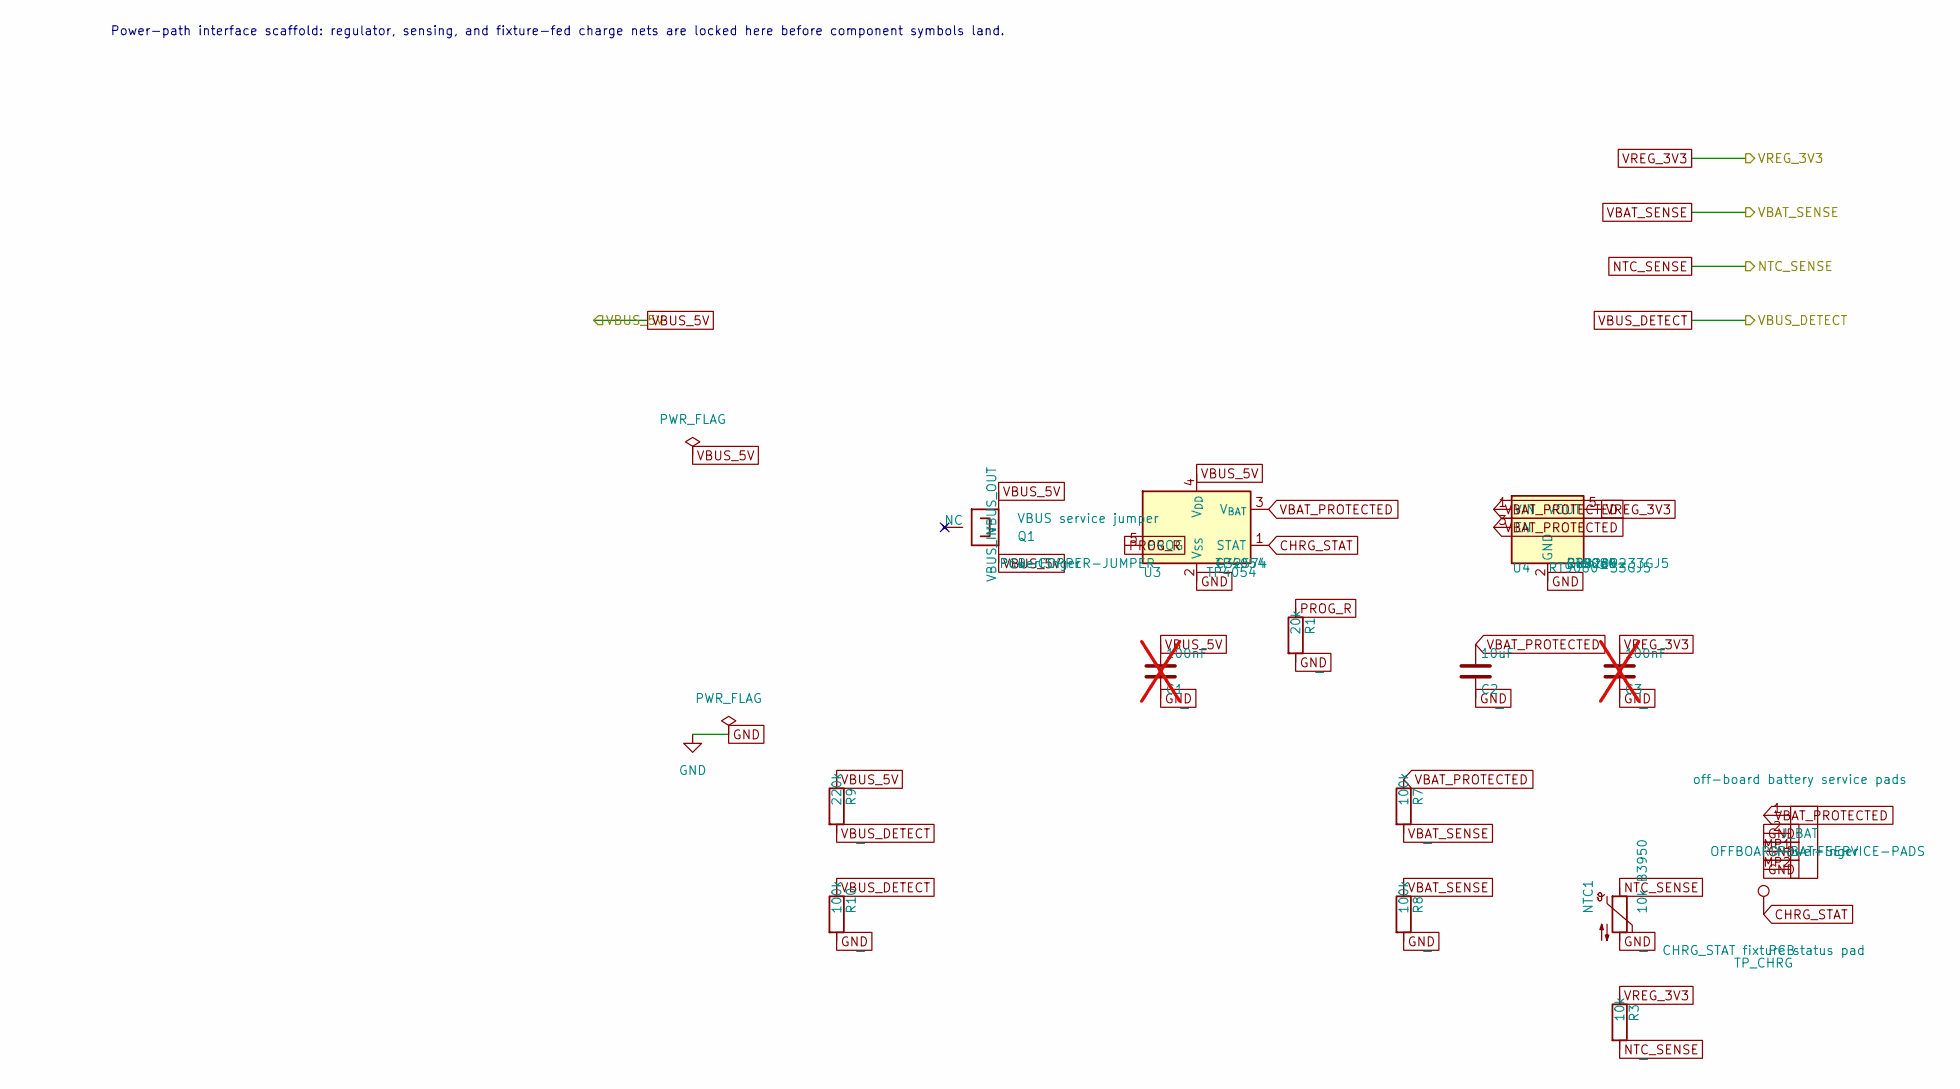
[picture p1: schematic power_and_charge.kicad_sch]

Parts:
C1, C3: 100nF; C_0402_1005Metric; not fitted
C2: 10uF; C_0603_1608Metric
J_BAT: off-board battery service pads; Offboard_Battery_Service_SameNet; mfg_part_num OFFBOARD-BAT-SERVICE-PADS
NTC1: 10k B3950; Thermistor_NTC_0402_1005Metric
Q1: VBUS service jumper; VBUS_Service_Jumper_SOT23Land; mfg_part_num PCB-COPPER-JUMPER
R1: 20k; R_0402_1005Metric
R3: 10k; R_0402_1005Metric
R7, R8, R10: 100k; R_0402_1005Metric
R9: 220k; R_0402_1005Metric
TP_CHRG: CHRG_STAT fixture status pad; TestPoint_Pad_D1.0mm_FirstBoard
U3: TP4054; SOT-23-5; mfg_part_num TP4054; lcsc C32574
U4: RT9080-33GJ5; RT9080_33GJ5_SOT23_5_ServiceClearance; mfg_part_num RT9080-33GJ5; lcsc C882092

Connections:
CHRG_STAT: TP_CHRG.1, U3.1 (CHRG)
NTC_SENSE: NTC1.1, R3.2; also elsewhere on the board
PROG_R: R1.1, U3.5 (PROG)
VBAT_PROTECTED: C2.1, J_BAT.1 (VBAT+), R7.1, U3.3 (BAT), U4.1 (VIN), U4.3 (EN)
VBAT_SENSE: R7.2, R8.1; also elsewhere on the board
VBUS_DETECT: R9.2, R10.1; also elsewhere on the board
VREG_3V3: C3.1, R3.1, U4.5 (VOUT); also elsewhere on the board

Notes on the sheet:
Power-path interface scaffold: regulator, sensing, and fixture-fed charge nets are locked here before component symbols land.

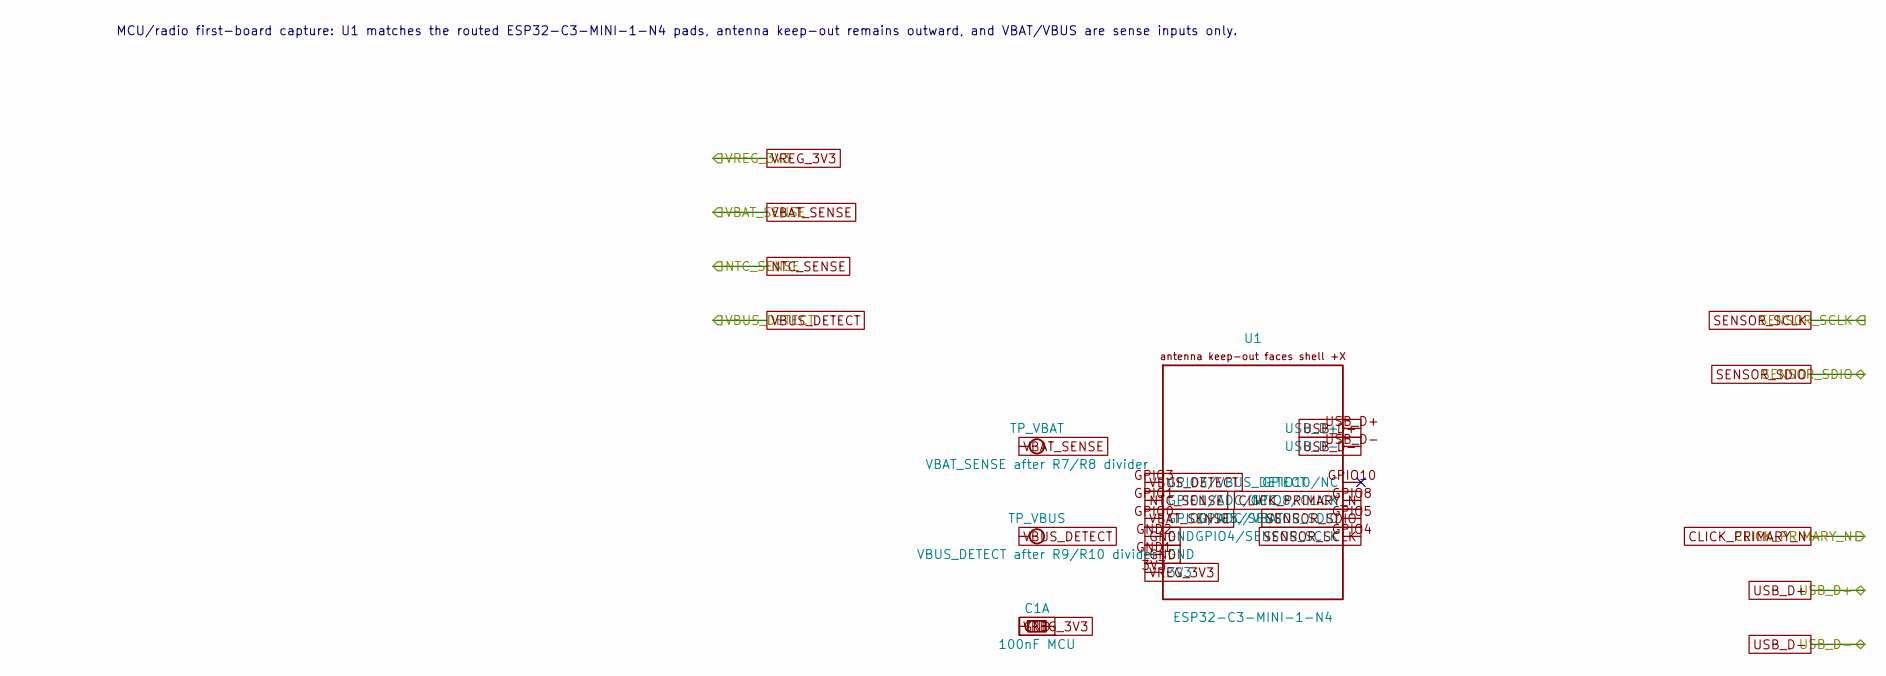
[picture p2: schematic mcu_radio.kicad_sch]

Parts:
C1A: 100nF MCU; C_0402_1005Metric
TP_VBAT: VBAT_SENSE after R7/R8 divider; TestPoint_Pad_D1.0mm
TP_VBUS: VBUS_DETECT after R9/R10 divider; TestPoint_Pad_D1.0mm
U1: ESP32-C3-MINI-1-N4; ESP32-C3-MINI-1_N4_Module_P0_AntennaRight

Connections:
CLICK_PRIMARY_N: U1.GPIO8 (GPIO8_CLICK); also elsewhere on the board
NTC_SENSE: U1.GPIO1 (GPIO1_ADC); also elsewhere on the board
SENSOR_SCLK: U1.GPIO4 (GPIO4_SENSOR_SCLK); also elsewhere on the board
SENSOR_SDIO: U1.GPIO5 (GPIO5_SENSOR_SDIO); also elsewhere on the board
USB_D+: U1.USB_D+ (GPIO19_USB_D+); also elsewhere on the board
USB_D-: U1.USB_D- (GPIO18_USB_D-); also elsewhere on the board
VBAT_SENSE: TP_VBAT.1, U1.GPIO0 (GPIO0_ADC); also elsewhere on the board
VBUS_DETECT: TP_VBUS.1, U1.GPIO3 (GPIO3_VBUS_DETECT); also elsewhere on the board
VREG_3V3: C1A.1, U1.3V3; also elsewhere on the board

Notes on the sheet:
MCU/radio first-board capture: U1 matches the routed ESP32-C3-MINI-1-N4 pads, antenna keep-out remains outward, and VBAT/VBUS are sense inputs only.

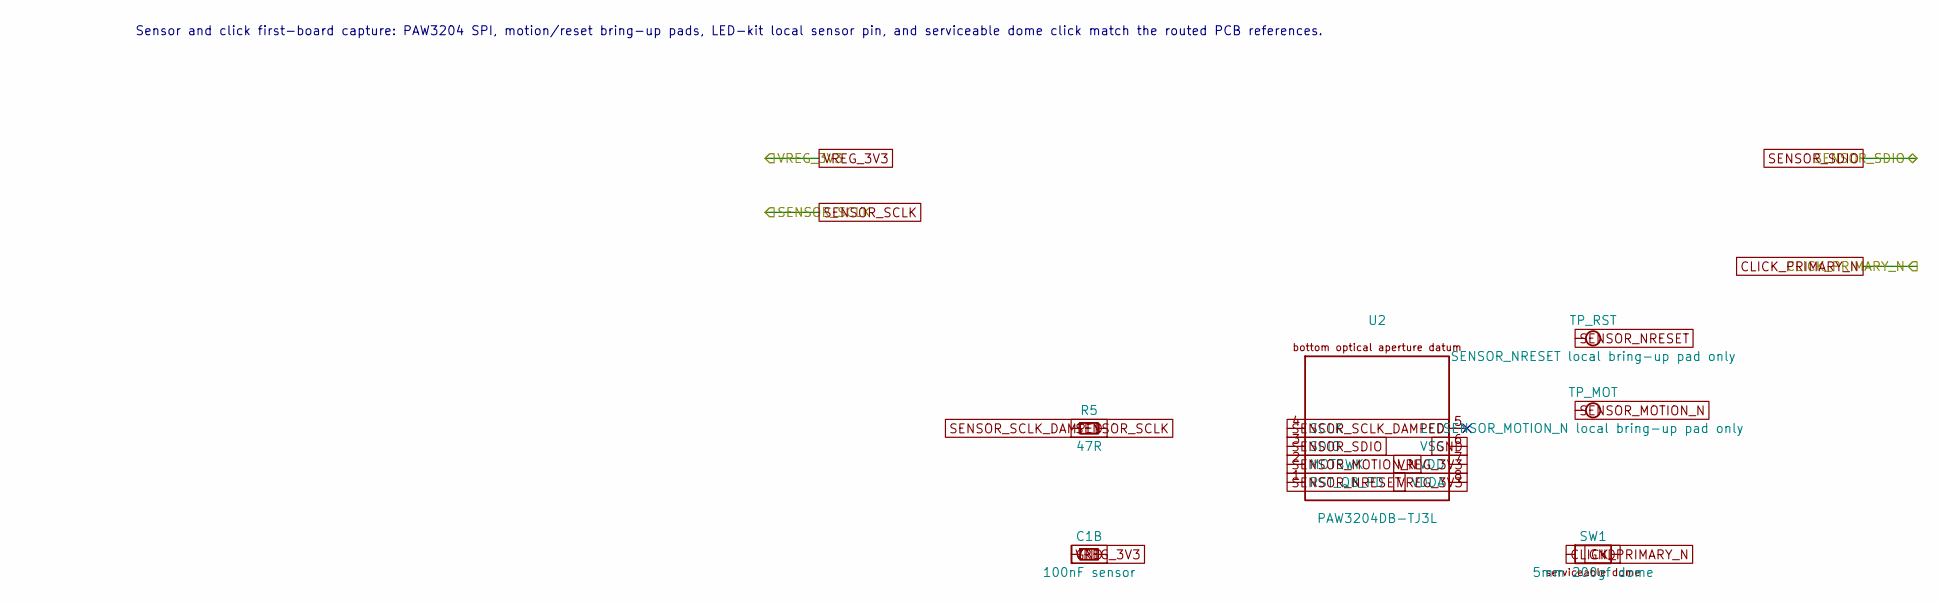
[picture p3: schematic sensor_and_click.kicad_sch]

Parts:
C1B: 100nF sensor; C_0402_1005Metric
R5: 47R; R_0402_1005Metric
SW1: 5mm 200gf dome; Snap_Dome_5mm_TwoPad_Serviceable
TP_MOT: SENSOR_MOTION_N local bring-up pad only; TestPoint_Pad_D1.0mm
TP_RST: SENSOR_NRESET local bring-up pad only; TestPoint_Pad_D1.0mm
U2: PAW3204DB-TJ3L; PAW3204DB_TJ3L_Staggered_DIP8_Bottom_ApertureDatum

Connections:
CLICK_PRIMARY_N: SW1.1 (DOME_CENTER); also elsewhere on the board
SENSOR_MOTION_N: TP_MOT.1, U2.2 (MOTSWK)
SENSOR_NRESET: TP_RST.1, U2.1 (RST_QB_PD)
SENSOR_SCLK: R5.1; also elsewhere on the board
SENSOR_SCLK_DAMPED: R5.2, U2.4 (SCLK)
SENSOR_SDIO: U2.3 (SDIO); also elsewhere on the board
VREG_3V3: C1B.1, U2.7 (VDD), U2.8 (VDDA); also elsewhere on the board

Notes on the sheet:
Sensor and click first-board capture: PAW3204 SPI, motion/reset bring-up pads, LED-kit local sensor pin, and serviceable dome click match the routed PCB references.

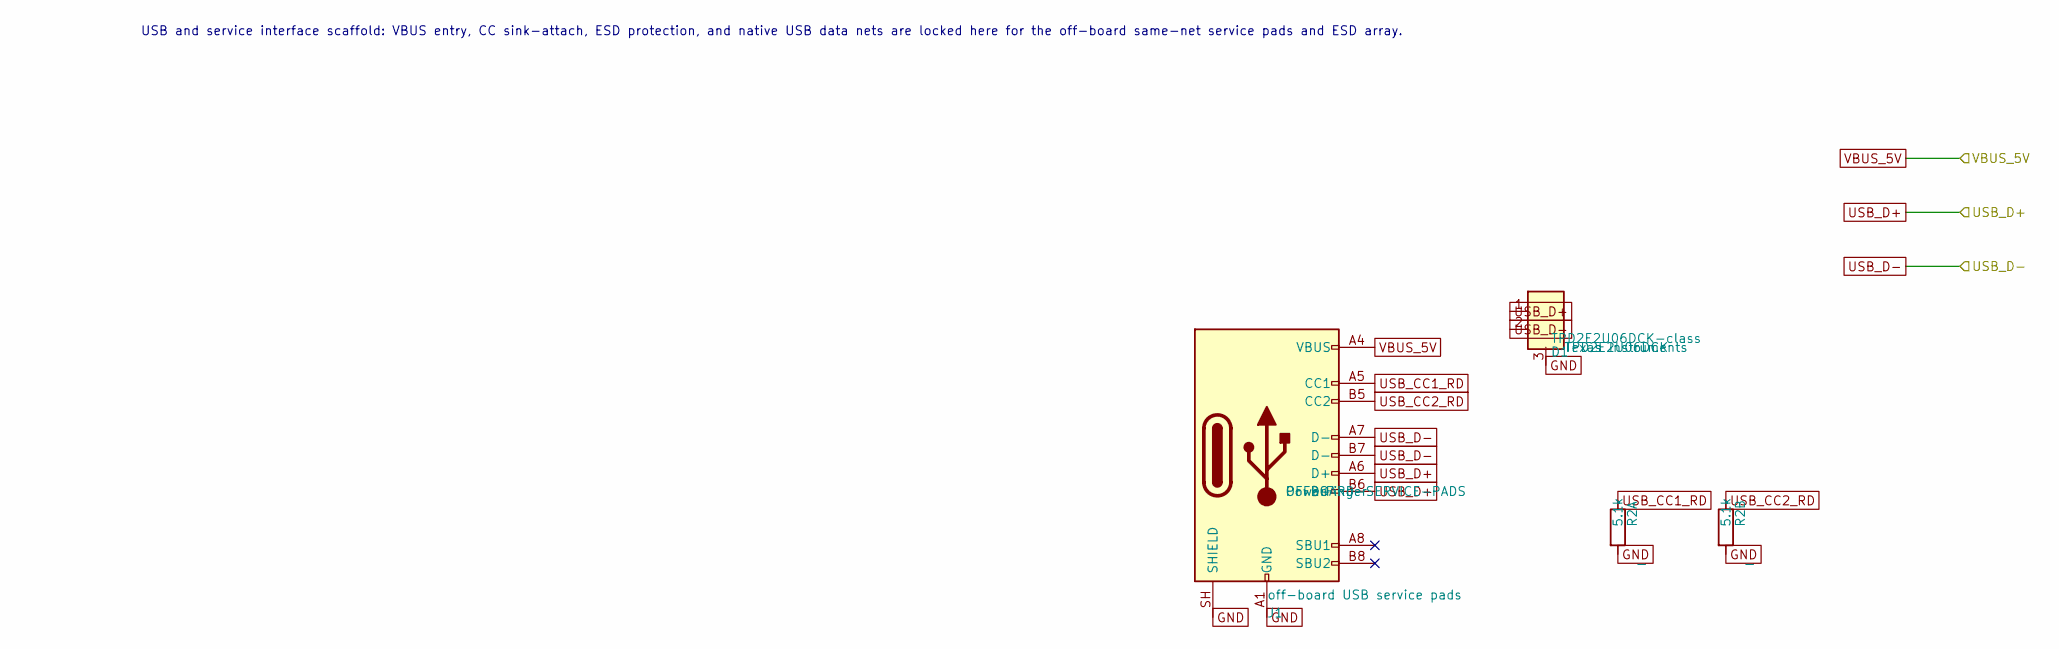
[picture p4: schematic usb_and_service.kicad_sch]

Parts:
D1: TPD2E2U06DCK-class; SOT-323_SC-70; mfg_part_num TPD2E2U06DCK
J1: off-board USB service pads; Offboard_USB_Service_SameNet; mfg_part_num OFFBOARD-SERVICE-PADS
R2A, R2B: 5.1k; R_0402_1005Metric

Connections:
USB_CC1_RD: J1.A5 (CC1), R2A.1
USB_CC2_RD: J1.B5 (CC2), R2B.1
USB_D+: D1.1 (IO1), J1.A6 (D+), J1.B6 (D+); also elsewhere on the board
USB_D-: D1.2 (IO2), J1.A7 (D-), J1.B7 (D-); also elsewhere on the board

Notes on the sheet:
USB and service interface scaffold: VBUS entry, CC sink-attach, ESD protection, and native USB data nets are locked here for the off-board same-net service pads and ESD array.

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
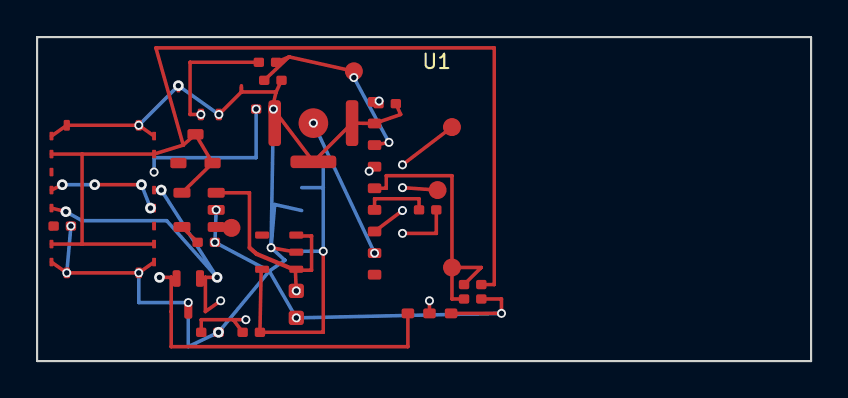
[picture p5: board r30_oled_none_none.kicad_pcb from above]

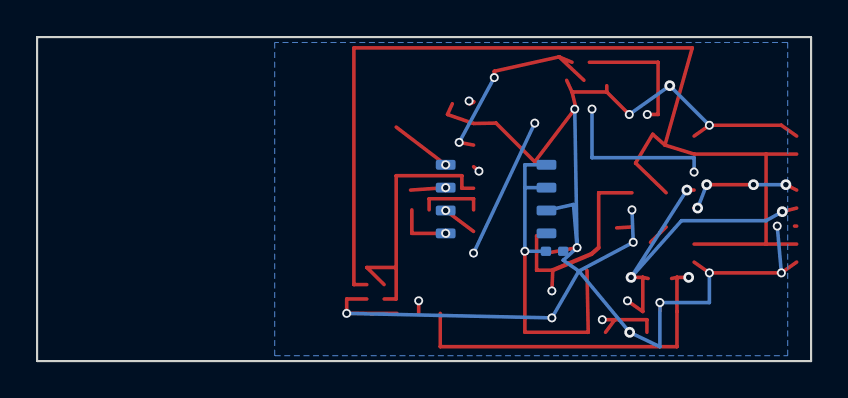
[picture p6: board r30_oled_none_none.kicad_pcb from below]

Board: 4 copper layers, 43.0 x 18.0 mm, 27 parts (2 on the bottom side), 19 nets.

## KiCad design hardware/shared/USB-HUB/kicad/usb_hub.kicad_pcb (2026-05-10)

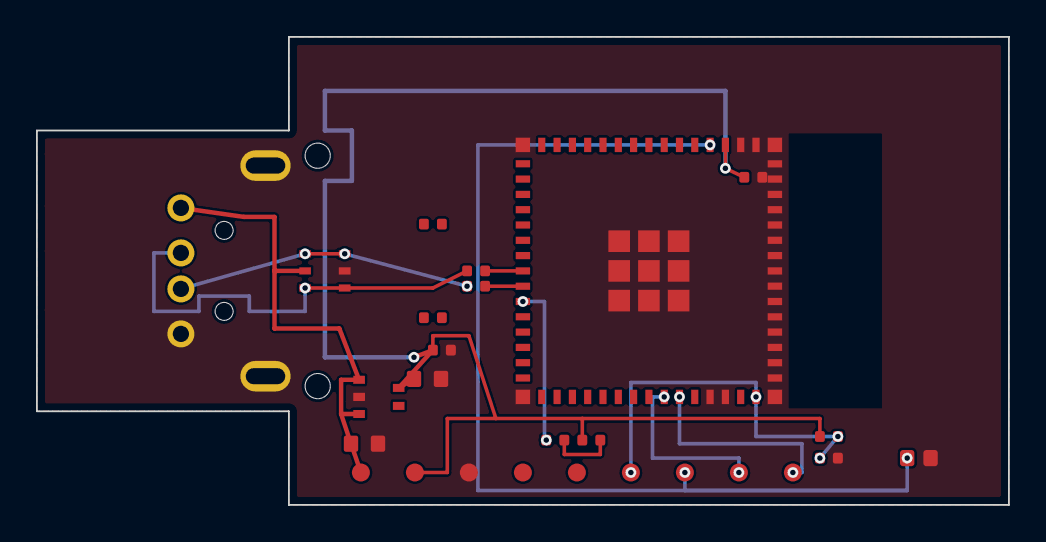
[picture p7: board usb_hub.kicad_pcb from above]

Board: 2 copper layers, 54.0 x 26.0 mm, 28 parts (0 on the bottom side), 13 nets.

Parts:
C1A, C1B: 100nF; C_0402_1005Metric_FirstBoard
C2: 10uF; C_0603_1608Metric_FirstBoard
C3: 1uF; C_0603_1608Metric_FirstBoard
C4: 1uF; C_0402_1005Metric_FirstBoard
C5: DNI USB_D- no-net; C_0402_1005Metric_FirstBoard
C6: DNI USB_D+ no-net; C_0402_1005Metric_FirstBoard
D1: USBLC6-2SC6; SOT-23-6_FirstBoard
J1: SOFNG USB-05; USB_A_Plug_SOFNG_USB-05
LED1: green; LED_0402_1005Metric_FirstBoard
MH1, MH2: shell clamp; MountingHole_1.4mm_Clamp
R1A, R1B: 22R; R_0402_1005Metric_FirstBoard
R2: 1k; R_0402_1005Metric_FirstBoard
R3: 10k; R_0402_1005Metric_FirstBoard
SW1: BOOT_SERVICE; PadActuated_Boot_Service
TP1: VBUS; TestPoint_Pad_D1.0mm_FirstBoard
TP2: 3V3; TestPoint_Pad_D1.0mm_FirstBoard
TP3: GND; TestPoint_Pad_D1.0mm_FirstBoard
TP4: D- trace access; TestPoint_Pad_D1.0mm_FirstBoard
TP5: D+ trace access; TestPoint_Pad_D1.0mm_FirstBoard
TP6: EN; TestPoint_Pad_D1.0mm_FirstBoard
TP7: BOOT; TestPoint_Pad_D1.0mm_FirstBoard
TP8: TX; TestPoint_Pad_D1.0mm_FirstBoard
TP9: RX; TestPoint_Pad_D1.0mm_FirstBoard
U1: ESP32-S3-MINI-1-N8; ESP32-S3-MINI-1-N8_FirstBoard
U2: RT9080-33GJ5; SOT-23-5_FirstBoard

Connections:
/controls_and_indicators/BOOT_N: SW1.1, TP7.1, U1.4
/controls_and_indicators/EN: C4.1, R3.2, TP6.1, U1.45
/controls_and_indicators/GND: C1A.2, C1B.2, C2.1, C3.1, C4.2, D1.2, J1.4, J1.SH1, J1.SH2, SW1.2, TP3.1, U1.1, U1.2, U1.42, U1.43, U1.46, U1.47, U1.48, U1.49, U1.50, U1.51, U1.52, U1.53, U1.54, U1.55, U1.56, U1.57, U1.58, U1.59, U1.60, U1.61, U1.62, U1.63, U1.64, U1.65, U2.2
/controls_and_indicators/LED_LIMIT: LED1.2, R2.2
/controls_and_indicators/LED_STATUS: LED1.1, U1.25
/controls_and_indicators/UART_RX_DBG: TP9.1, U1.40
/controls_and_indicators/UART_TX_DBG: TP8.1, U1.39
/controls_and_indicators/VREG_3V3: C1A.1, C1B.1, C3.2, R2.1, R3.1, TP2.1, U1.3, U2.5
/mcu_radio/USB_D+: R1B.2, U1.24
/mcu_radio/USB_D-: R1A.2, U1.23
/usb_and_power/USB_D+_CONN: D1.3, D1.4, J1.3, R1B.1
/usb_and_power/USB_D-_CONN: D1.1, D1.6, J1.2, R1A.1
/usb_and_power/VBUS_5V: C2.2, D1.5, J1.1, TP1.1, U2.1, U2.3

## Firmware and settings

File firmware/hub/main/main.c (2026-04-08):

// SPDX-License-Identifier: MIT
// PowerFinger USB Hub Dongle Firmware — Entry Point
//
// The hub is a BLE central + composite USB device. It:
// 1. Scans for PowerFinger ring peripherals over BLE
// 2. Pairs, bonds, and receives HID reports from up to 4 rings
// 3. Maps each ring to a role (cursor, scroll, modifier) via the role engine
// 4. Composes all ring inputs into a single USB HID mouse report
// 5. Presents as one USB HID mouse plus a CDC control port to the host OS

#include <stdio.h>
#include "esp_log.h"
#include "esp_ota_ops.h"
#include "esp_task_wdt.h"
#include "nvs_flash.h"
#include "hal_timer.h"
#include "ble_central.h"
#include "companion_cdc.h"
#include "hub_settings.h"
#include "role_engine.h"
#include "gesture_engine.h"
#include "event_composer.h"
#include "hub_identity.h"
#include "usb_hid_mouse.h"

static const char *TAG = "powerfinger_hub";

// Poll for rings stuck in GATT discovery at a human timescale, not every
// USB tick. 1s granularity is plenty for a 10s discovery timeout.
#define DISCOVERY_TIMEOUT_CHECK_MS 1000

// H1: USB HID send failure escalation.
// After this many consecutive send errors (excluding HAL_ERR_BUSY which is
// transient), the hub restarts. At 1ms poll rate, 5000 = 5 seconds of
// continuous failure — long enough to survive brief USB bus resets, short
// enough to not leave a user without input indefinitely.
#define USB_SEND_FAIL_THRESHOLD 5000

static void sync_persisted_gestures_to_event_composer(void)
{
    for (uint8_t trigger = GESTURE_TRIGGER_CURSOR_SCROLL_CLICK;
         trigger <= GESTURE_TRIGGER_ALL_THREE_CLICK;
         trigger++) {
        event_composer_set_gesture_action(trigger, gesture_engine_get_action(trigger));
    }
}

// --- Callbacks from BLE central ---

static void on_ring_report(uint8_t ring_index, const hub_ring_report_t *report, void *arg)
{
    (void)arg;

    // Feed into event composer. Role is cached on connect so the hot path does
    // not take the role-engine mutex for every BLE notification.
    event_composer_feed(ring_index, report->buttons, report->dx, report->dy);
}

static void on_ring_connection(uint8_t ring_index, bool connected, void *arg)
{
    (void)arg;

    if (connected) {
        ring_role_t role = ROLE_CURSOR;
        uint8_t mac[6];
        if (ble_central_get_mac(ring_index, mac) == HAL_OK) {
            role = role_engine_get_role(mac);
        } else {
            ESP_LOGW(TAG, "ring %d connected but MAC lookup failed, defaulting role to CURSOR",
                     ring_index);
        }
        event_composer_mark_connected(ring_index, role);
        ESP_LOGI(TAG, "ring %d connected, role=%s",
                 ring_index, role_engine_role_name(role));
    } else {
        ESP_LOGI(TAG, "ring %d disconnected", ring_index);
        // Critical: immediately release buttons to prevent stuck state
        event_composer_ring_disconnected(ring_index);
    }
}

static void fill_companion_hub_info(companion_protocol_hub_info_t *info_out, void *arg)
{
    (void)arg;

    if (!info_out) {
        return;
    }

    hub_settings_snapshot_t settings = {0};
    hub_settings_get(&settings);

    *info_out = (companion_protocol_hub_info_t) {
        .firmware_revision = hub_identity_firmware_revision(),
        .hardware_revision = hub_identity_hardware_revision(),
        .connected_rings = ble_central_connected_count(),
        .max_rings = HUB_MAX_RINGS,
        .usb_poll_ms = settings.usb_poll_ms,
        .scan_policy = settings.scan_policy,
        .expected_rings = settings.expected_rings,
    };
}

// --- Main ---

void app_main(void)
{
    ESP_LOGI(TAG, "PowerFinger USB hub dongle starting");

    // Initialize NVS (required for BLE bonding and role persistence)
    esp_err_t ret = nvs_flash_init();
    if (ret == ESP_ERR_NVS_NO_FREE_PAGES ||
        ret == ESP_ERR_NVS_NEW_VERSION_FOUND) {
        ESP_LOGW(TAG, "NVS partition erased, re-initializing");
        ESP_ERROR_CHECK(nvs_flash_erase());
        ret = nvs_flash_init();
    }
    ESP_ERROR_CHECK(ret);

    // Initialize components. The hub depends on role persistence, BLE ingest,
    // and the composite USB output/control surface, so fail fast if any of
    // those cannot come up cleanly at boot.
    if (role_engine_init() != HAL_OK) {
        // Mutex allocation failure means OOM at boot — restart rather than
        // running the role engine without synchronization.
        ESP_LOGE(TAG, "role engine init failed (OOM) — restarting");
        esp_restart();
    }
    if (gesture_engine_init() != HAL_OK) {
        ESP_LOGE(TAG, "gesture engine init failed — restarting");
        esp_restart();
    }
    if (hub_settings_init() != HAL_OK) {
        ESP_LOGE(TAG, "hub settings init failed — restarting");
        esp_restart();
    }
    event_composer_init();
    sync_persisted_gestures_to_event_composer();
    if (usb_hid_mouse_init() != HAL_OK) {
        ESP_LOGE(TAG, "USB HID init failed — hub has no output path");
        esp_restart();
    }
    if (ble_central_init(on_ring_report, on_ring_connection, NULL) != HAL_OK) {
        ESP_LOGE(TAG, "BLE central init failed — hub cannot function");
        esp_restart();
    }
    if (ble_central_set_scan_policy(hub_settings_get_scan_policy(),
                                    hub_settings_get_expected_rings()) != HAL_OK) {
        ESP_LOGE(TAG, "BLE central scan policy init failed — restarting");
        esp_restart();
    }
    companion_cdc_config_t companion_cfg = {
        .fill_hub_info = fill_companion_hub_info,
        .cb_arg = NULL,
    };
    if (companion_cdc_start(&companion_cfg) != HAL_OK) {
        ESP_LOGE(TAG, "USB companion CDC init failed — restarting");
        esp_restart();
    }

    // Register main task with watchdog (hub must not hang silently)
    esp_task_wdt_add(NULL);

    // Confirm this firmware is valid — cancels automatic rollback.
    // Must be called after all critical init succeeds and the watchdog is
    // armed, so a broken build that hangs here still gets rolled back.
    esp_ota_mark_app_valid_cancel_rollback();

    ESP_LOGI(TAG, "hub ready, scanning for rings...");
    ESP_LOGI(TAG, "hub identity: fw=%s hw=%s",
             hub_identity_firmware_revision(),
             hub_identity_hardware_revision());

    // --- Main loop: compose and send USB HID reports at 1ms ---
    // Track whether the previous report was non-zero so we always send
    // a final zero report to release buttons. Suppressing the zero report
    // after disconnect would leave a stuck button on the host — the exact
    // accessibility hazard the event composer is designed to prevent.
    bool prev_report_nonzero = false;

    uint32_t last_discovery_check_ms = hal_timer_get_ms();

    // H1: consecutive USB HID send failure counter
    uint32_t usb_fail_count = 0;

    while (1) {
        uint32_t now = hal_timer_get_ms();
        composed_report_t report;
        event_composer_compose(&report);

        bool report_nonzero = (report.buttons != 0 ||
                               report.cursor_dx != 0 || report.cursor_dy != 0 ||
                               report.scroll_v != 0 || report.scroll_h != 0);

        if (report_nonzero || prev_report_nonzero) {
            hal_status_t send_rc = usb_hid_mouse_send(&report);
            if (send_rc == HAL_OK || send_rc == HAL_ERR_BUSY) {
                usb_fail_count = 0;
            } else {
                usb_fail_count++;
                if (usb_fail_count >= USB_SEND_FAIL_THRESHOLD) {
                    ESP_LOGE(TAG, "USB HID send failed %lu consecutive times — restarting",
                             (unsigned long)USB_SEND_FAIL_THRESHOLD);
                    esp_restart();
                }
                if ((usb_fail_count % 1000) == 1) {
                    ESP_LOGW(TAG, "USB HID send error: %d (%lu consecutive)",
                             send_rc, (unsigned long)usb_fail_count);
                }
            }
        }

        prev_report_nonzero = report_nonzero;

        if ((now - last_discovery_check_ms) >= DISCOVERY_TIMEOUT_CHECK_MS) {
            // H8: disconnect rings stuck in GATT discovery
            ble_central_check_discovery_timeout();
            last_discovery_check_ms = now;
        }

        esp_task_wdt_reset();
        hal_timer_delay_ms(hub_settings_get_usb_poll_ms());
    }
}

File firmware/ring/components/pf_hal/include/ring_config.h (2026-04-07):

// SPDX-License-Identifier: MIT
// PowerFinger — Ring configuration constants
//
// Every threshold and timeout is a named constant with rationale.
// No magic numbers in firmware code.

#pragma once

#include <stdint.h>

// --- Sensor noise ---
// Sensor deltas below this do not count as motion and do not reset the idle timer.
// Without this, sensor jitter prevents the device from ever entering idle.
#define NOISE_THRESHOLD_OPTICAL     2    // counts (PAW3204/ADNS-2080)
#define NOISE_THRESHOLD_HALL        5    // counts (DRV5053, TBD after calibration)

// --- Main loop ---
// Sensor poll rate. Matches the minimum BLE connection interval (7.5ms rounds
// up to 15ms on most hosts) and keeps CPU load proportional to HID report rate.
#define SENSOR_POLL_INTERVAL_MS     15

// Repeated sensor read failures should degrade motion input instead of
// immediately rebooting the device out from under the user. 50 polls at 15ms
// is about 750ms of continuous failure before falling back to click-only mode.
#define SENSOR_READ_FAIL_DEGRADE_THRESHOLD 50

// Once motion input is unavailable, attempt sensor wake/reinit at a human
// timescale instead of hammering the bus on every 15ms main-loop iteration.
#define SENSOR_RECOVERY_ATTEMPT_MS 1000

// If HID notifications fail continuously for this long, restart to recover the
// BLE stack instead of silently staying connected but unusable.
#define BLE_HID_SEND_RESTART_MS    5000

// --- State machine timing ---
// Duration of no motion before transitioning from ACTIVE to IDLE.
// At this point, connection interval reverts from 7.5ms to 15ms.
#define IDLE_TRANSITION_MS          250

// Duration of no activity (no motion above noise threshold, no click)
// before entering deep sleep from IDLE.
// Override via Kconfig POWERFINGER_SLEEP_TIMEOUT_MS per form factor.
#ifdef CONFIG_POWERFINGER_SLEEP_TIMEOUT_MS
#define SLEEP_TIMEOUT_MS            CONFIG_POWERFINGER_SLEEP_TIMEOUT_MS
#else
#define SLEEP_TIMEOUT_MS            45000  // 45 seconds
#endif

// Maximum time to advertise before giving up and entering deep sleep.
// Prevents battery drain from indefinite advertising.
#define RECONNECT_TIMEOUT_MS        60000  // 60 seconds

// --- Battery ---
// LiPo cells suffer permanent damage below ~3.0V. Cut off above the knee.
#define LOW_VOLTAGE_CUTOFF_MV       3200

// How often to sample VBAT ADC during connected states.
// NVS writes for logging are deferred to idle periods.
#define BATTERY_CHECK_INTERVAL_MS   60000  // 60 seconds

// --- Click dead zone ---
// Pressing the finger down causes micro-movement of the sensor.
// Dead zone suppresses X/Y deltas while the dome is actuated.
// Dead zone exit requires BOTH conditions to be met. These are the persisted
// first-boot defaults; runtime values may be changed over BLE and stored in NVS.
#define DEAD_ZONE_TIME_MS           50   // minimum hold time before exit
#define DEAD_ZONE_TIME_MS_MAX       2000 // BLE-configurable upper bound
#define DEAD_ZONE_DISTANCE          10   // minimum accumulated counts before exit
#define DEAD_ZONE_DISTANCE_MAX      255  // BLE-configurable upper bound
#define DEAD_ZONE_DISTANCE_PRO      15   // Pro: account for LRA vibration contribution (A6 analysis)

// Additional suppression during haptic pulse (Pro tier, piezo+LRA click)
// 35ms covers Sharp Click waveform 17 (~20ms) + mechanical decay margin (A6 analysis)
#define HAPTIC_SUPPRESS_MS          35

// Click debounce (dome switch bounce is typically 1-5ms)
#define CLICK_DEBOUNCE_MS           5

// --- Calibration ---
// Boot-time calibration samples sensor at rest to establish zero offset.
#define CALIBRATION_SAMPLE_COUNT    50     // number of readings
#define CALIBRATION_SAMPLE_PERIOD_MS 2     // ms between readings (~100ms total)

// If standard deviation of sensor readings during calibration exceeds this,
// the device was moving during boot — retry calibration.
#define CALIBRATION_MOTION_THRESHOLD 5     // stddev in counts

// Delay between calibration retries
#define CALIBRATION_RETRY_DELAY_MS  500

// Maximum calibration attempts before using zero offset
#define CALIBRATION_MAX_RETRIES     3

// Overall calibration timeout. If calibration_run() exceeds this wall-clock
// duration, it aborts regardless of retry count. Prevents infinite hang if
// sensor_read() blocks. Conservative: 2× worst-case normal duration.
#define CALIBRATION_TIMEOUT_MS      5000

// --- Runtime settings ---
// DPI multiplier uses 0.1x units so the ring can scale deltas without float.
#define DPI_MULTIPLIER_DEFAULT      10   // 1.0x native sensor scale
#define DPI_MULTIPLIER_MIN          1    // 0.1x
#define DPI_MULTIPLIER_MAX          255  // 25.5x

// Flash erase/commit can take tens to hundreds of milliseconds, so settings
// writes stay in RAM until the ring leaves the active HID path.
#define SETTINGS_FLUSH_RETRY_MS     1000
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

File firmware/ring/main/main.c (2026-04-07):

// SPDX-License-Identifier: MIT
// PowerFinger Ring Firmware - Entry Point

#include "app_runtime.h"

static const powerfinger_app_config_t s_ring_app_config = {
    .log_tag = "powerfinger",
    .firmware_name = "PowerFinger ring",
};

void app_main(void)
{
    powerfinger_app_main(&s_ring_app_config);
}

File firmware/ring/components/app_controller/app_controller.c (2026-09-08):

// SPDX-License-Identifier: MIT
// PowerFinger — Ring app controller implementation

#include "app_controller.h"

#include <string.h>

#include "ble_config.h"
#include "hal_ble.h"
#include "ring_config.h"

#ifdef ESP_PLATFORM
#include "esp_log.h"
static const char *TAG = "app_ctrl";
#define APP_CTRL_LOGI(...) ESP_LOGI(TAG, __VA_ARGS__)
#define APP_CTRL_LOGW(...) ESP_LOGW(TAG, __VA_ARGS__)
#define APP_CTRL_LOGE(...) ESP_LOGE(TAG, __VA_ARGS__)
#else
#define APP_CTRL_LOGI(...) (void)0
#define APP_CTRL_LOGW(...) (void)0
#define APP_CTRL_LOGE(...) (void)0
#endif

static void execute_actions(app_controller_t *controller,
                            const ring_actions_t *actions,
                            uint32_t now_ms)
{
    if (!controller || !actions) {
        return;
    }

    if (actions->stop_advertising || actions->enter_deep_sleep) {
        controller->advertising_started_ms = 0;
    }
    if (actions->start_advertising) {
        controller->advertising_started_ms = now_ms;
    }

    if (actions->stop_advertising) {
        hal_ble_stop_advertising();
    }
    if (actions->start_advertising) {
        if (hal_ble_start_advertising(BLE_ADVERTISE_TIMEOUT_MS) != HAL_OK) {
            controller->advertising_started_ms = 0;
            APP_CTRL_LOGE("advertising start failed — entering deep sleep");
            power_manager_enter_sleep(true);
            return;
        }
    }
    if (actions->enter_deep_sleep) {
        power_manager_enter_sleep(true);
    }
}

static void note_connected_transition(app_controller_t *controller,
                                      uint16_t conn_interval_1_25ms,
                                      const char *reason)
{
    if (!controller) {
        return;
    }

    power_manager_on_connect();

    if (controller->runtime_health) {
        ring_runtime_health_reset_hid_send(controller->runtime_health);
    }

    if (controller->diagnostics) {
        ring_diagnostics_note_connected(controller->diagnostics,
                                        conn_interval_1_25ms);
        app_controller_log_diagnostics_snapshot(reason, controller->diagnostics);
    }

    controller->previous_buttons = 0;
}

static void note_disconnected_transition(app_controller_t *controller,
                                         const char *reason)
{
    if (!controller) {
        return;
    }

    if (controller->primary_dead_zone) {
        dead_zone_reset(controller->primary_dead_zone);
    }
    if (controller->secondary_dead_zone) {
        dead_zone_reset(controller->secondary_dead_zone);
    }

    power_manager_on_disconnect();

    if (controller->runtime_health) {
        ring_runtime_health_reset_hid_send(controller->runtime_health);
    }

    if (controller->diagnostics) {
        ring_diagnostics_note_disconnected(controller->diagnostics);
        app_controller_log_diagnostics_snapshot(reason, controller->diagnostics);
    }

    controller->previous_buttons = 0;
}

void app_controller_init(app_controller_t *controller,
                         ring_diagnostics_t *diagnostics,
                         ring_runtime_health_t *runtime_health,
                         dead_zone_ctx_t *primary_dead_zone,
                         dead_zone_ctx_t *secondary_dead_zone)
{
    if (!controller) {
        return;
    }

    memset(controller, 0, sizeof(*controller));
    controller->diagnostics = diagnostics;
    controller->runtime_health = runtime_health;
    controller->primary_dead_zone = primary_dead_zone;
    controller->secondary_dead_zone = secondary_dead_zone;
}

void app_controller_log_diagnostics_snapshot(const char *reason,
                                             const ring_diagnostics_t *diagnostics)
{
    if (!reason || !diagnostics) {
        return;
    }

    ring_diag_snapshot_t snapshot = ring_diagnostics_snapshot(diagnostics);
    uint32_t interval_centims = (uint32_t)snapshot.conn_interval_1_25ms * 125U;
    uint32_t interval_ms_whole = interval_centims / 100U;
    uint32_t interval_ms_frac = interval_centims % 100U;

    if (snapshot.conn_interval_1_25ms == 0) {
        APP_CTRL_LOGI(
            "diag[%s]: state=%s sensor=%s cal=%s bond=%s conn=unknown rejected=%s batt=%u%% (%lumV)"
#ifdef CONFIG_POWERFINGER_FORM_FACTOR_PEN
            " drv5032=%s spur=%u"
#endif
            ,
            reason,
            ring_state_name(snapshot.ring_state),
            ring_diag_sensor_state_name(snapshot.sensor_state),
            snapshot.calibration_valid ? "valid" : "pending",
            ring_diag_bond_state_name(snapshot.bond_state),
            snapshot.conn_param_rejected ? "yes" : "no",
            snapshot.battery_pct,
            (unsigned long)snapshot.battery_mv
#ifdef CONFIG_POWERFINGER_FORM_FACTOR_PEN
            ,
            snapshot.drv5032_wake_enabled ? "enabled" : "disabled",
            snapshot.spurious_wake_count
#endif
        );
        return;
    }

    APP_CTRL_LOGI(
        "diag[%s]: state=%s sensor=%s cal=%s bond=%s conn=%lu.%02lums rejected=%s batt=%u%% (%lumV)"
#ifdef CONFIG_POWERFINGER_FORM_FACTOR_PEN
        " drv5032=%s spur=%u"
#endif
        ,
        reason,
        ring_state_name(snapshot.ring_state),
        ring_diag_sensor_state_name(snapshot.sensor_state),
        snapshot.calibration_valid ? "valid" : "pending",
        ring_diag_bond_state_name(snapshot.bond_state),
        (unsigned long)interval_ms_whole,
        (unsigned long)interval_ms_frac,
        snapshot.conn_param_rejected ? "yes" : "no",
        snapshot.battery_pct,
        (unsigned long)snapshot.battery_mv
#ifdef CONFIG_POWERFINGER_FORM_FACTOR_PEN
        ,
        snapshot.drv5032_wake_enabled ? "enabled" : "disabled",
        snapshot.spurious_wake_count
#endif
    );
}
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

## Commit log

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2026-03-24 docs: add initial BOMs for P0/P1 prototypes and USB hub
    Pre-schematic bills of materials with specific part numbers, supplier
    references, and acceptable alternatives:
    - R30-OLED-NONE-NONE: optical ring, ~$9 BOM (P0)
    - R30-BALL-NONE-NONE: ball+Hall ring, ~$11 BOM (P1)
    - WSTD-BALL-NONE-NONE: ball+Hall wand, ~$14 BOM (P1)
    - USB-HUB: BLE central + USB HID dongle, ~$5-6 BOM (P0)
    CSV format per OSHWA convention. Key components: ESP32-C3-MINI-1-N4
    (LCSC C2838502), PAW3204DB-TJ3L optical sensor, SS49E Hall sensors,
    Snaptron SQ-series snap domes, TP4054 charge controller, ESP32-S3-MINI-1-N8
    for hub. All parts multi-sourced per project hard rule.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
    [R30-BALL-NONE-NONE.csv, R30-OLED-NONE-NONE.csv, USB-HUB.csv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]
2026-03-26 docs: add consumer tiers, power budget, wand competitive analysis
    Three new documents:
    - CONSUMER-TIERS.md: two-tier Standard ($9) / Pro ($17) product model
    - POWER-BUDGET.md: component-level power estimates from datasheets
    - WAND-COMPETITIVE.md: pen mouse market gap, accessibility case, patent analysis
    Key findings driving BOM and spec changes:
    - ESP32-C3 achieves 3–6 days battery (not 1–2 weeks) — power target corrected
    - AP2112K LDO (55µA Iq) dominated deep sleep 11:1 — swapped to RT9080 (0.5µA)
    - Charge resistor was 2kΩ (6.25C on 80mAh, kills cell in 100 cycles) — fixed to 10kΩ
    - SS49E Hall sensors (6mA each) swapped to DRV5053 (3mA) with power gating
    - Connection interval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
    [R30-BALL-NONE-NONE.csv, R30-OLED-NONE-NONE.csv, WSTD-BALL-NONE-NONE.csv]
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2026-03-26 feat(firmware): implement ring + hub firmware through Phase 4
    Complete firmware implementation for ESP32-C3 ring and ESP32-S3 hub,
    all runnable on commodity dev boards before custom hardware arrives.
    Architecture:
    - Platform HAL: 9 portable headers + ESP-IDF implementations, no
    platform types in any interface header (nRF52840 migration = module swap)
    - Ring: table-driven state machine (5 states, 10 events), PAW3204
    bit-banged optical driver, click with dual-condition dead zone,
    adaptive power management, BLE HID mouse with NimBLE
    - Hub: BLE central (up to 4 rings), role engine with NVS persistence,
    event composer with spinlock-protected multi-ring composition,
    USB HID output via T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
    [partitions.csv]
2026-03-27 fix(firmware): medium-priority audit fixes — role engine, sensor, OTA, BLE
    Role engine (M4+M5+M6):
    - NVS writes moved outside mutex to avoid blocking NimBLE task during
    flash erase (up to 200ms)
    - Added versioned NVS blob format with validation on load — firmware
    updates won't corrupt role assignments
    - Added role_engine_forget() for stale entry eviction — new rings can
    get persisted roles after replacing old hardware
    PAW3204 sensor driver (M8):
    - Cache GPIO direction to avoid calling hal_gpio_init on every bit —
    reduces 64 gpio_config register writes per sensor read to ~2 direction
    changes per register operation
    OTA (M9):
    - Store partition pointer in OTA context from beg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
    [paw3204.c, role_engine.c]
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2026-03-27 fix(firmware): round 2 audit fixes — supervision, type safety, error propagation
    Supervision (Armstrong audit):
    - Hub on_reset now clears all ring connection state and notifies
    event composer — prevents stuck buttons after NimBLE host reset
    - hal_ble_start_advertising now propagates ble_gap_adv_start failure
    instead of always returning HAL_OK — state machine detects when
    advertising actually failed
    Type safety (API ergonomics audit):
    - Replace void* handles with forward-declared struct pointers —
    passing a timer handle to an SPI function is now a compile error
    - Remove duplicate hal_gpio_enable_wake (hal_sleep_configure_wake_gpio
    is the canonical API, both called the same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
    [ble_central.c, hal_gpio_esp.c]
2026-03-27 fix(firmware): finish remaining audit items — types, errors, supervision, tests
    Event sentinel + decoupling:
    - Add RING_EVT_NONE (-1) sentinel replacing RING_EVT_COUNT as "no event"
    - Decouple power_manager from ring_state.h with power_event_t enum —
    power manager is now reusable in wand firmware without ring state types
    HAL type safety:
    - hal_adc_channel_t typedef (prevents uint8_t confusion)
    - hal_spi_mode_t enum (prevents invalid mode values)
    - s_connected as atomic_bool in hal_ble_esp.c (ESP32-S3 dual-core safety)
    Error handling hardening:
    - execute_actions: advertising failure triggers deep sleep (was silent)
    - power_manager_init failure is now fatal (LiPo safety — no battery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
    [ble_central.c, main.c, power_manager.c]
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2026-03-27 fix(firmware+hw): apply audit fixes from prior session
    Bellman/reliability/data-integrity audit fixes:
    - event_composer: int32 accumulation + clamping for cursor_dx/dy overflow
    (accessibility hazard for multi-CURSOR-ring users at INT16 boundary)
    - ble_central: check ble_gap_conn_find and ble_gap_connect returns;
    log short HID reports instead of silently discarding; fix on_reset
    count-then-clear ordering
    - role_engine: fix flush_to_nvs stale-snapshot race via mutex-held snapshot
    - ring_config.h: HAPTIC_SUPPRESS_MS 20→35 (A6), add DEAD_ZONE_DISTANCE_PRO=15
    BOM corrections (all three ring/wand variants):
    - RPROG 10kΩ→20kΩ (50mA charge rate, thermal safety)
    - Remove YS8205 from opti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
    [R30-BALL-NONE-NONE.csv, R30-OLED-NONE-NONE.csv, WSTD-BALL-NONE-NONE.csv]
2026-03-27 fix(firmware): concurrency + reliability hardening (C2/H4/H5/R1-R3/R6-R7)
    C2: add portMUX_TYPE spinlock to ble_central.c for s_rings[]/s_connected_count
    — dual-core race between NimBLE task writes and app-core reads; BLE API calls
    moved outside critical sections, on_reset snapshots state under lock
    H4: implement deferred NVS writes in role_engine
    — NimBLE task now sets s_dirty + s_pending_blob under mutex and returns;
    actual flush (up to ~200ms) moved to role_engine_flush_if_dirty() called
    from hub main loop every ~1000 ticks (~1s)
    H5: fatal esp_restart() on role_engine OOM instead of warning-and-continue
    — running role engine without mutex on HAL_ERR_NO_MEM was unsynchro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
    [ble_central.c, main.c, power_manager.c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]
2026-03-27 fix(firmware): second audit pass — spinlock symmetry, safety guards, hardening
    H-NEW-1: fix asymmetric spinlock in ble_central.c — find_ring_by_conn() now
    called inside RINGS_LOCK() in DISCONNECT and NOTIFY_RX handlers, matching
    the discipline already applied in the CONNECT handler
    H-NEW-2: remove dead if(PKTLEN>=4) wrapper in NOTIFY_RX — always true after
    the short-report early break; merge artifact
    H-NEW-3: fix start_advertising() forward declaration void→int in hal_ble_esp.c
    — signature mismatch with definition was UB / potential compile error
    H-NEW-4: guard against unwakeable deep sleep in power_manager.c — if both
    GPIO and timer wake source config fail, restart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
    [ble_central.c, main.c, power_manager.c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]
2026-03-28 fix(firmware): CE-2, R12, M1-M3, M2 CCCD discovery, on_disc_chr spinlock
    CE-2: default_role_for_new_ring() scans occupied roles instead of using
    insertion index — forget+re-pair now assigns CURSOR if it is unoccupied
    rather than repeating the last-used index's role
    R12: hal_storage_set / hal_storage_commit return values now checked and
    logged in flush_to_nvs — NVS write failures are visible in diagnostics
    M2: replace val_handle+1 CCCD assumption with proper GATT descriptor
    discovery — add on_disc_dsc callback that searches [val_handle,
    val_handle+HID_DSC_SEARCH_RANGE] for UUID 0x2902 and subscribes after
    confirmation; CCCD write and subscribed flag moved into descriptor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
    [ble_central.c, role_engine.c]
2026-03-30 fix(firmware): 4 critical safety fixes from 6-agent audit cycle
    C1: Check CCCD write return — disconnect ring on failure instead of
    silently marking subscribed with no HID notifications arriving.
    C2: Validate conn_handle in GATT discovery callbacks — prevents slot
    reuse corruption when a ring disconnects mid-discovery and another
    ring claims the same slot before the callback fires.
    C3: Check ble_gap_conn_find return in ring REPEAT_PAIRING handler —
    prevents operating on uninitialized stack data (bond store corruption).
    C4: Zero buttons/accumulators on role change in event_composer_feed —
    prevents stuck-button hazard when role reassignment changes the
    button-to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
    [ble_central.c]
2026-03-30 fix(hub): 3 high-priority reliability fixes from audit cycle
    H1: USB HID send failure escalation — consecutive failure counter with
    5000-tick threshold (~5s). Restarts hub instead of logging warnings
    at 1kHz indefinitely while producing no useful output.
    H6: Defensive s_connected_count recompute in on_reset — recompute from
    array state after clearing, prevents theoretical underflow if a
    concurrent disconnect handler races with the reset.
    H8: GATT discovery timeout — rings connected but not subscribed within
    10s are disconnected. Prevents zombie slots that consume one of 4
    ring slots permanently when GATT discovery hangs.
    175 tests passing.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
    [ble_central.c, main.c]
2026-03-30 fix(firmware): 7 robustness fixes — return value checks, lock hygiene, NVS retry
    H3: Check ble_gap_security_initiate return on both hub and ring —
    log warning if encryption setup fails, proceed gracefully.
    H7: Check ble_gap_adv_set_fields return on ring — surface advertising
    data overflow errors that would make the ring invisible to the hub.
    M1: Check ble_gattc_disc_all_dscs return — log on failure, ring will
    hit H8 discovery timeout for cleanup.
    M2: Check ble_gattc_disc_all_chrs return — same pattern as M1.
    M3: Read s_connected_count under spinlock in start_scan() — consistency
    with all other access sites, prevents dual-core data race.
    M8: Re-set s_dirty flag on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
    [ble_central.c, role_engine.c]
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2026-04-04 feat(puck): stand up PowerPuck firmware build target
    Add firmware/puck/ as a new ESP-IDF build target sharing all ring
    components via EXTRA_COMPONENT_DIRS. The puck is electrically identical
    to the ring — same PAW3204 sensor, same snap dome click, same ESP32-C3
    MCU — with only configuration differences:
    - BLE device name: "PowerPuck" (Kconfig-driven, was hardcoded)
    - Idle-to-sleep timeout: 60s vs ring's 45s (survives typing pauses)
    - Log tag: "powerpuck"
    Prerequisite changes to shared headers:
    - ble_config.h: BLE_DEVICE_NAME now reads CONFIG_POWERFINGER_DEVICE_NAME
    with #ifdef fallback to "PowerFinger" for host tests
    - ring_config.h: SLEEP_TIMEOUT_MS now reads CONFIG_POWERFINGER_SLEE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
    [partitions.csv]
2026-04-04 feat(sensors): add ball+Hall and PMW3360 sensor drivers
    Implement two new sensor drivers behind the existing sensor_interface.h
    contract, selectable via Kconfig POWERFINGER_SENSOR_DRIVER choice:
    Ball+Hall (SENSOR_BALL_HALL):
    - 4x DRV5053 analog Hall sensors via hal_adc, differential pair
    computation for X/Y deltas, at-rest baseline calibration (50 samples),
    motion-during-cal rejection, Kconfig-tunable sensitivity factor
    - surface_confidence from baseline deviation, noise threshold from
    ring_config.h NOISE_THRESHOLD_HALL
    - Driver does not touch Hall power MOSFET — power manager owns that
    PMW3360 (SENSOR_PMW3360):
    - Standard SPI Mode 3 via hal_spi, 2MHz clock
    - SROM firmware upload o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
    [ball_hall.c, pmw3360.c]
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2026-04-07 fix(firmware): pre-hardware safety hardening + test coverage
    CRITICAL safety:
    - NTC thermal monitoring with B3950 beta equation (45°C cutoff, 40°C resume, 60°C emergency shutdown)
    - P-ch MOSFET charge control (default-disabled via hardware pull-up, Kconfig-gated)
    - USB VBUS detection with sleep suppression (thermal emergency overrides VBUS)
    - Cold-charge cutoff at 0°C (lithium plating prevention)
    - Overvoltage protection: disable charging if VBAT >= 4.25V
    - Deep sleep always disables charging (defense-in-depth alongside hardware pull-up)
    HIGH priority:
    - PAW3204 sensor test suite: 10 tests covering init, motion read, power cycle, error handling
    - GPIO read sequence mock for bit-banged p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
    [calibration.c, main.c, paw3204.c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]
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2026-04-24 feat(usb-hub): add native usb first-board pass
    Defensive publication:
    - Specific sensing mechanism: no surface sensor on the hub; native USB ESP32-S3 service/programming and HID bridge capture for the PowerFinger BLE input family.
    - Form factor and angle: straight inline direct-plug USB-A dongle board, first-pass 54 x 26 mm layout with reinforced SOFNG USB-05 plug retention.
    - Intended use case: offline accessible first-board bring-up, repair, programming, and native-USB service for PowerFinger ring/wand development.
    - BOM estimate: keeps the active USB-HUB packet inside the current ~$5-6 first-board BOM intent.
    Verification:
    - git diff --check -- hardware/shared/USB-HUB
    - KiCad CLI E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
    [controls_and_indicators.kicad_sch, mcu_radio.kicad_sch, usb_and_power.kicad_sch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]
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2026-04-25 fix(usb-hub): clean native-usb dongle drc parity
    Direct-plug native USB hub dongle for accessibility pointing and OCR composition; no sensing mechanism change; BOM intent remains ~-6.
    [controls_and_indicators.kicad_sch, mcu_radio.kicad_sch, usb_and_power.kicad_sch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]
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2026-04-29 feat(hardware): land charge-gate safety BOM, sense/status starter parts, and kicad-cli baseline check
    Adds Q2/R6 (logic-safe charge-gate driver) and starter R7-R11 sense/status
    divider+pull-up lines to the active R30-OLED-NONE-NONE BOM CSV so the firmware
    sense contract is no longer aspirational. Captures the current ERC/DRC counts
    for both R30 (ERC=34, DRC=324, unconnected=41, parity=27) and USB-HUB (ERC=50,
    DRC=27 footprint-library only) as kicad/CURRENT-VIOLATIONS.md snapshots so the
    manifests cannot quietly drift past those red baselines. Wires kicad-cli ERC
    plus DRC --schematic-parity into scripts/verify-firmware-local.sh behind
    opt-in --with-kicad / --kicad-only / --kicad-strict flags,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
    [R30-OLED-NONE-NONE.csv]
2026-04-29 trial(mcp-sch): populate R30 power_and_charge sub-sheet via kicad-sch-api
    Adds 17 charge-path BOM components (U3, U4, Q1, Q2, R1, R3, R4, R6, R7,
    R8, R9, R10, R11, NTC1, C1, C2, C3) to the power_and_charge sub-sheet
    using stock KiCad symbols + footprints. The lib_symbols block aggregates
    correctly (the specific defect that disqualified kicad-mcp-pro v3.1.3
    in the prior trial). All 5 existing hierarchical labels preserved
    verbatim with original UUIDs.
    Trial-only commit. Do not merge until BDFL review per the trial brief.
    [power_and_charge.kicad_sch]
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2026-04-29 fix(bom): split R30 C1 Qty=2 row into distinct C1 and C3 designators
    The active BOM previously listed C1 with Qty=2 sharing one ref-prefix,
    which kicad-sch-api's reference-format validator rejects (a non-standard
    "C1_alt" form fails) and which conflicts with C2 already in use for the
    LDO input bulk. Split into:
    C1 (100nF) — TP4054 input decoupling at U3.VCC
    C2 (10µF) — LDO input bulk at U4.VIN (unchanged)
    C3 (100nF) — LDO output decoupling at U4.VOUT
    Aligns BOM with the populated schematic capture (commit f47aa99).
    [R30-OLED-NONE-NONE.csv]
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2026-05-02 fix(usb-hub): pin local first-board footprints
    Design disclosure: sensing mechanism none; form factor stepped USB-A direct-plug USB-HUB dongle; intended use offline BLE HID composition and service access for accessibility; BOM estimate ~$5-6 packet target.
    Move first-board commodity/support footprints into the source-controlled PowerFinger_USB library and update the packet verification story to all-severity PCB DRC clean.
    [controls_and_indicators.kicad_sch, mcu_radio.kicad_sch, usb_and_power.kicad_sch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]
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2026-05-03 fix(r30): clean schematic erc library baseline
    Design disclosure: sensing mechanism PAW3204-class optical tracking; form factor R30-OLED-NONE-NONE fingertip ring, active 30-degree ring packet; intended use BLE HID pointing for accessibility; BOM estimate ~$5.30-9.45.
    Materialize the project-local PowerFinger symbol and PowerFinger_Ring footprint libraries, wire sheet-interface labels, keep PAW3204 reset/motion local to sensor test pads, and update the verified KiCad snapshot to ERC=0, DRC=349, unconnected=41, parity=118.
    [mcu_radio.kicad_sch, power_and_charge.kicad_sch, r30_oled_none_none.kicad_pcb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]
2026-05-03 feat(r30): add board firmware profile
    Add an R30-OLED-NONE-NONE sdkconfig fragment, verifier profile mode, resolved Kconfig contract docs, and the ESP-IDF include needed for the snap-dome ISR attribute.
    [click_dome.c]
2026-05-03 fix(r30): reduce pcb schematic parity
    Sensing mechanism: PAW3204 optical surface tracking.\nForm factor and angle: R30 30-degree ring, OLED/NONE/NONE active lane.\nIntended use: accessibility-first BLE HID pointing first-board validation.\nBOM estimate: active R30 prototype remains about .30-.45, target about .
    [power_and_charge.kicad_sch, r30_oled_none_none.kicad_pcb]
2026-05-03 fix(r30): reconcile schematic net parity
    Sensing mechanism: PAW3204 optical surface tracking.
    Form factor and angle: R30 30-degree ring, OLED/NONE/NONE active lane.
    Intended use: accessibility-first BLE HID pointing first-board validation.
    BOM estimate: active R30 prototype remains about .30-.45, target about .
    [mcu_radio.kicad_sch, power_and_charge.kicad_sch, r30_oled_none_none.kicad_pcb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]
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2026-05-03 fix(r30): model battery connector shield pads
    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
    [power_and_charge.kicad_sch]
2026-05-03 fix(r30): reduce first routing drc blockers
    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
    [r30_oled_none_none.kicad_pcb]
2026-05-03 fix(r30): cut routing drc blockers
    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
    [r30_oled_none_none.kicad_pcb]
2026-05-03 fix(r30): move dome away from mcu pad column
    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
    [r30_oled_none_none.kicad_pcb, r30_oled_none_none_shell_blank.scad]
2026-05-03 fix(r30): correct charge service endpoints
    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
    [r30_oled_none_none.kicad_pcb]
2026-05-03 fix(r30): move charge bias off usb cc row
    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
    [r30_oled_none_none.kicad_pcb]
2026-05-03 fix(r30): move charger switch off usb data row
    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
    [r30_oled_none_none.kicad_pcb]
2026-05-03 fix(r30): separate usb data lanes
    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
    [r30_oled_none_none.kicad_pcb]
2026-05-04 fix(r30): contain usb service edge
    Form factor and angle: R30 30-degree ring, OLED/NONE/NONE active lane; left USB-C service edge widened to the 43 x 18 mm board datum.
    BOM estimate: active R30 prototype remains about .30-.45, target about ; outline and routing-only change adds no BOM line.
    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
    [r30_oled_none_none.kicad_pcb, r30_oled_none_none_shell_blank.scad]
2026-05-04 fix(r30): clear connector cluster routing debt
    Form factor and angle: R30 30-degree ring, OLED/NONE/NONE active lane; connector-side CC2 and thermistor divider routing cleanup.
    BOM estimate: active R30 prototype remains about .30-.45, target about ; routing and placement-only change adds no BOM line.
    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
    [r30_oled_none_none.kicad_pcb]
2026-05-04 fix(r30): reroute usb data escape
    Form factor and angle: R30 30-degree ring, OLED/NONE/NONE active lane; A-side USB D+/D- escape moved onto B.Cu under the charger cluster.
    BOM estimate: active R30 prototype remains about .30-.45, target about ; routing-only change adds no BOM line.
    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
    [r30_oled_none_none.kicad_pcb]
2026-05-04 fix(r30): connect mirrored usb data pads
    Form factor and angle: R30 30-degree ring, OLED/NONE/NONE active lane; mirrored USB-C B6/B7 data pads routed into the existing data escape.
    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
    [r30_oled_none_none.kicad_pcb]
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2026-05-04 fix(r30): replace d1 rail clamp esd
    Sensing mechanism: PAW3204 optical surface tracking with rail-less dual USB data ESD protection on the service connector.
    Form factor and angle: R30 30-degree ring, OLED/NONE/NONE active lane; D1 changes from USBLC6 SOT-23-6 rail clamp to TPD2E2U06DCK-class SC-70/SOT-323 data shunt.
    Intended use: accessibility-first BLE HID pointing first-board validation with offline USB service/debug retained.
    BOM estimate: active R30 prototype remains about .30-.45, target about ; D1 stays in the same about /bin/zsh.03-/bin/zsh.10 ESD protection class.
    [R30-OLED-NONE-NONE.csv, r30_oled_none_none.kicad_pcb, usb_and_service.kicad_sch]
2026-05-04 fix(r30): stitch service edge ground return
    Sensing mechanism: PAW3204 optical surface tracking with rail-less USB data ESD protection and a connector-side GND/shield return for the service edge.
    Form factor and angle: R30 30-degree ring, OLED/NONE/NONE active lane; the routed change stitches J1 ground contacts, shell stakes, R2B, R1, J_BAT MP1, and D1/NTC return without moving the shell-bound USB-C connector.
    Intended use: accessibility-first BLE HID pointing first-board validation with offline USB service/debug retained and repairable connector shielding.
    BOM estimate: active R30 prototype remains about .30-.45, target about ; this is a copper-only grounding cleanup with no BOM increase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
    [r30_oled_none_none.kicad_pcb]
2026-05-04 fix(r30): route battery ground fanout
    Sensing mechanism: PAW3204 optical surface tracking with rail-less USB data ESD protection and a localized battery-side GND fanout cleanup for the service/debug edge.
    Form factor and angle: R30 30-degree ring, OLED/NONE/NONE active lane; this routed change preserves the shell-bound USB-C, JST-SH battery connector, snap dome, and antenna geometry while doglegging R8/J_BAT MP2, tying J_BAT pad 2, moving J_BAT MP1 to a B-side return via, and joining R2A/left SW1/Q2 source into one local GND chain.
    Intended use: accessibility-first BLE HID pointing first-board validation with offline USB service/debug retained, repairable battery/service hardware, and hone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
    [r30_oled_none_none.kicad_pcb]
2026-05-04 fix(r30): normalize first-board via rules
    Sensing mechanism: PAW3204 optical surface tracking with rail-less USB data ESD protection and board-rule-compliant first-board signal/power vias.
    Form factor and angle: R30 30-degree ring, OLED/NONE/NONE active lane; this routed change preserves the shell-bound USB-C, JST-SH battery connector, snap dome, sensor, and antenna geometry while bringing the six remaining sub-minimum vias to 0.50 mm diameter / 0.30 mm drill.
    Intended use: accessibility-first BLE HID pointing first-board validation with offline USB service/debug retained and KiCad-red packet status reported honestly.
    BOM estimate: active R30 prototype remains about .30-.45, target about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
    [r30_oled_none_none.kicad_pcb]
2026-05-04 fix(r30): route sensor rail off paw column
    Sensing mechanism: PAW3204 optical surface tracking with RT9080-derived VREG_3V3 routed to the sensor VDD/VDDA pads through a board-rule-compliant B-side trunk.
    Form factor and angle: R30 30-degree ring, OLED/NONE/NONE active lane; this routed change preserves the shell-bound USB-C, JST-SH battery connector, snap dome, sensor aperture, and antenna geometry while moving the sensor-rail via off the PAW3204 LED/GND pad column.
    BOM estimate: active R30 prototype remains about .30-.45, target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
    [r30_oled_none_none.kicad_pcb]
2026-05-04 fix(r30): land charge pulldown ground cleanup
    Sensing mechanism: PAW3204 optical surface tracking with charge-enable pulldown grounding and PAW3204 LED test access adjusted in the routed first-board packet.
    Form factor and angle: R30 30-degree ring, OLED/NONE/NONE active lane; this routed change preserves the shell-bound USB-C connector, JST-SH battery connector, snap dome, sensor aperture, antenna geometry, and 43 x 18 mm board envelope while moving only R6 and the non-shell-bound TP_LEDKIT pad.
    BOM estimate: active R30 prototype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
    [r30_oled_none_none.kicad_pcb]
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

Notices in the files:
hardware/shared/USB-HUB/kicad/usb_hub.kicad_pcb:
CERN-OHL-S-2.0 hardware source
